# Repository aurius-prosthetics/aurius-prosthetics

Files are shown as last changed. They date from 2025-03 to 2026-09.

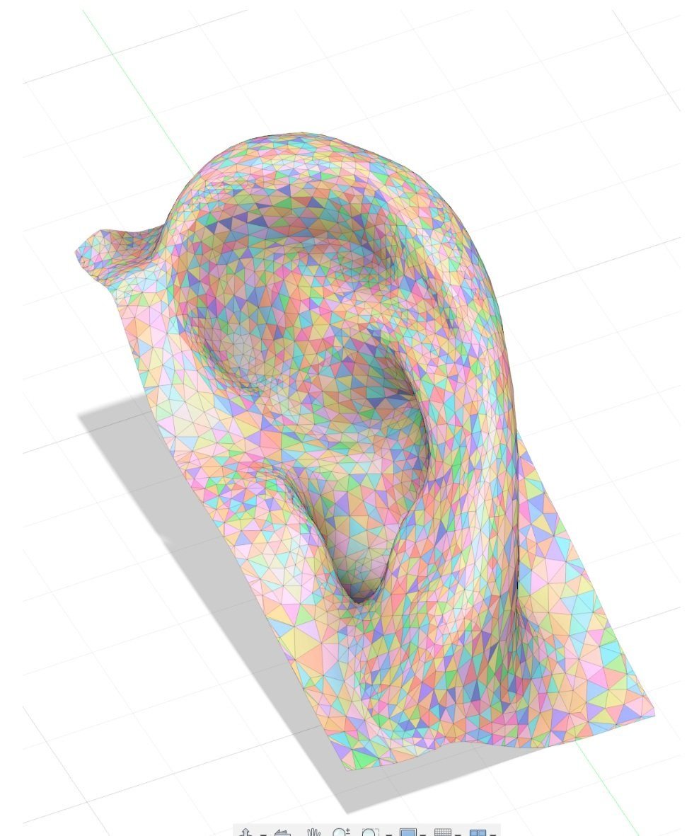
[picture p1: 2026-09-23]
images/front_img3.jpg

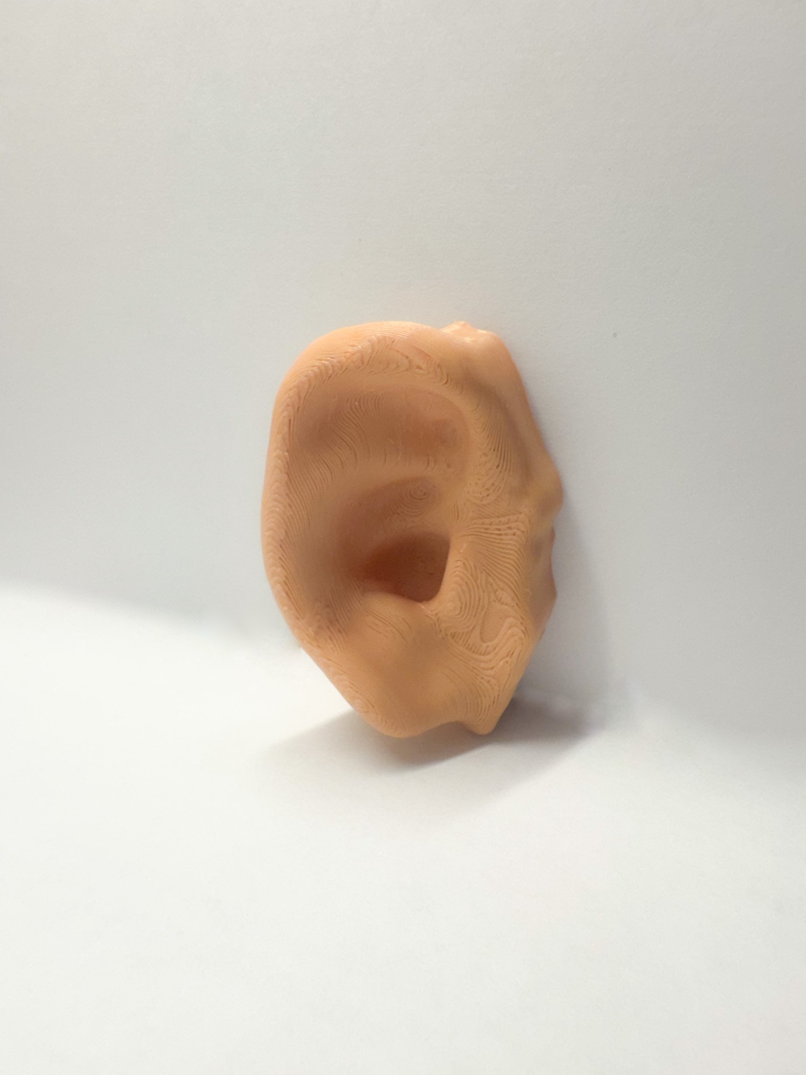
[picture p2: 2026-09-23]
images/gallery_ear.jpg

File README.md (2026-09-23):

# Aurius Prosthetics 🦻




**Open-source initiative for 3D-printed prosthetics**

[📧 Contact Us](mailto:aurius.king@gmail.com)
---
Access our Website : (https://aurius-prosthetics.github.io/aurius-prosthetics/#home)
## About Aurius

Hi, I'm King Oung, founder of Aurius Prosthetics. We're revolutionizing accessibility in prosthetic ear design through cutting-edge 3D printing technology. Our mission is to provide **affordable, accessible, and aesthetically realistic** prosthetic solutions for individuals with microtia, empowering them with greater confidence and self-expression.

By leveraging innovative materials and user-centered design, we bridge the gap between medical necessity and personal identity, ensuring everyone has access to high-quality, customizable prosthetics.

## ✨ Key Features

- **🎨 Customizable Design** - Personalized ear shapes and sizes
- **💰 Cost-Effective** - Open-source designs reduce costs dramatically
- **📐 Precision Crafted** - Generated using LiDAR technology for accurate proportions
- **🧲 Multiple Attachment Options** - Magnetic, clip-on, or suction mounting
- **🤝 Community-Driven** - Open-source CAD files for collaboration
- **🪶 Lightweight & Realistic** - Skin-like texture using flexible materials

## 🚀 Quick Start

### What You'll Need
- 3D printer compatible with flexible filaments
- **Recommended Filament:** Filaflex 82A or similar TPE/TPU
- Basic assembly tools

### Printing Process
1. **Download** your desired `.3MF` file from the [models folder](./models)
2. **Print** using TPE/TPU filament for flexibility (PLA works for prototypes)
3. **Assemble** following our detailed guide
4. **Customize** using provided CAD files as needed

*Compatible with Bambu Labs printers - adjust settings accordingly*

## 📁 Repository Structure

```
aurius-prosthetics/
├── models/                    # 3D printable files
│   ├── Ear1.3mf              # Prosthetic ear model #1
│   ├── Ear2.3mf              # Prosthetic ear model #2
│   ├── Ear3.3mf              # Prosthetic ear model #3
│   └── README Before Printing.md  # Important pre-print instructions
├── HowToPrint.md             # Step-by-step printing instructions
├── assembly-guide.md         # Assembly and attachment methods
├── material-specs.md         # Material specifications and settings
├── CONTRIBUTING.md           # Guidelines for contributors
├── LICENSE                   # MIT License
├── index.html               # Project website page
└── README.md                # This file
```

## 📖 Detailed Guides

- [🖨️ **Printing Guide**](./HowToPrint.md) - Step-by-step printing instructions
- [🔧 **Assembly Guide**](./assembly-guide.md) - Attachment methods and fitting  
- [📋 **Material Specifications**](./material-specs.md) - Filament types and properties

## 🛣️ Roadmap

- [x] **Phase 1:** Initial prototype development (LiDAR scanning, modeling)
- [x] **Phase 2:** Testing attachment methods and materials
- [x] **Phase 3:** Community feedback integration
- [x] **Phase 4:** Global Medical professional collaboration

## 🤝 Contributing

We welcome contributions from the community! Whether you're a:
- **Developer** - Improve CAD designs or documentation
- **Medical Professional** - Provide clinical insights
- **User** - Share feedback and experiences
- **Maker** - Test prints and suggest improvements

## 💬 Community & Support

- **Questions?** Reach out directly to us at [aurius.king@gmail.com] or on social media
- **Success Stories** - We'd love to hear about your prints!
- **Medical Consultation** - Always consult healthcare professionals for medical advice

## 📄 License

This project is licensed under the [MIT License](LICENSE) - see the LICENSE file for details.

## 🙏 Acknowledgments

Special thanks to:
- The open-source community for inspiration and support
- Medical professionals providing guidance
- Early adopters and testers
- Everyone working to make assistive technology more accessible

---

**Made with ❤️ for accessibility and inclusion**

*Aurius Prosthetics - Reimagining the future of prosthetic innovation*

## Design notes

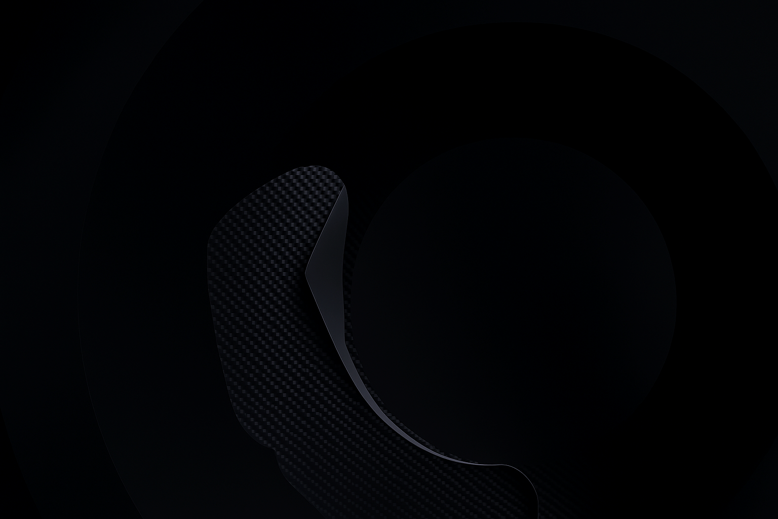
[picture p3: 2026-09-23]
images/hero.png

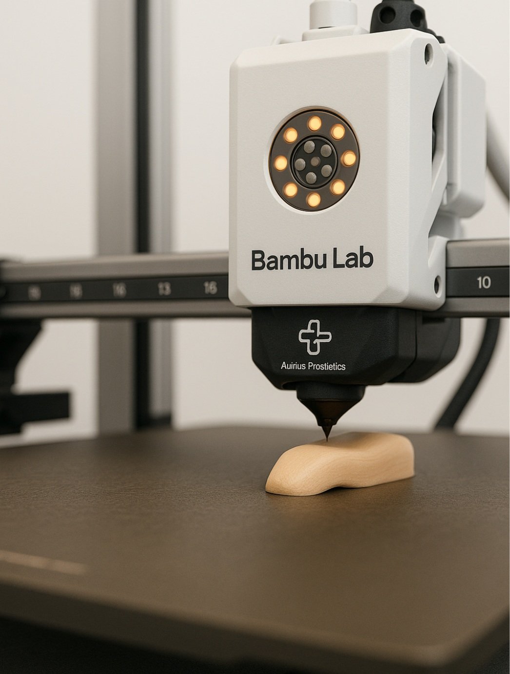
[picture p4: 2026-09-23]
images/front_bg.jpg

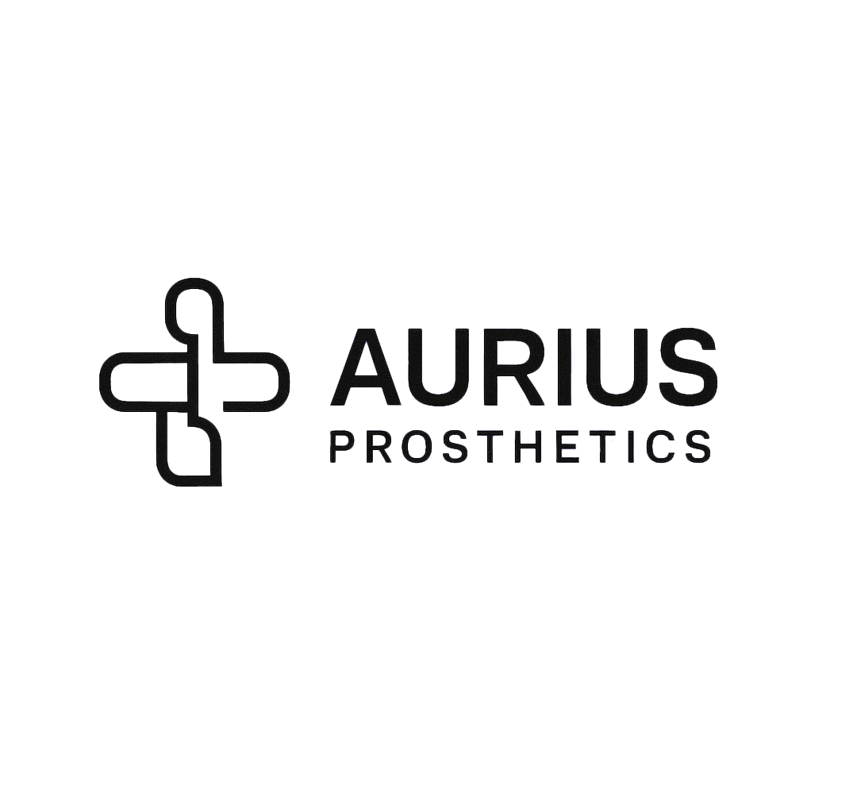
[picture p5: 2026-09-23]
images/front_img5.png

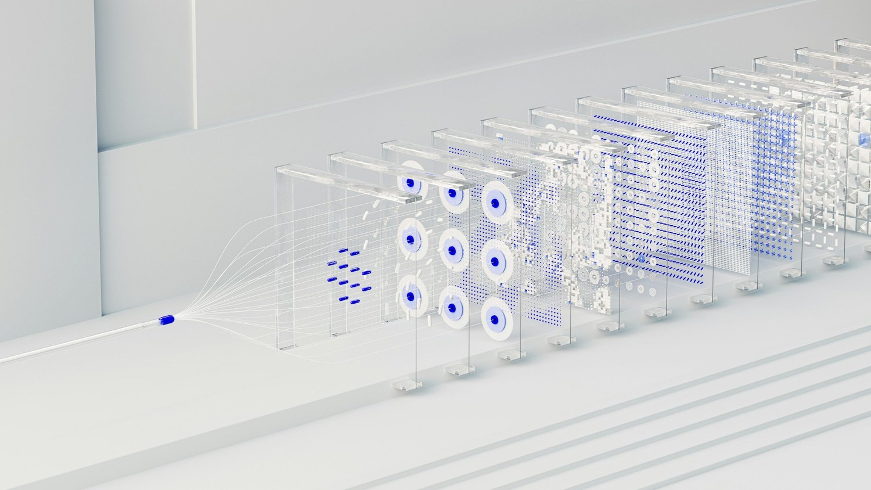
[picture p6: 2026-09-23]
images/contact_bg.jpg

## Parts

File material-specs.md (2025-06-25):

# Material Specifications 📋

## Recommended Filaments

### Primary Choice: TPE/TPU (Flexible)
**Recommended Brand: Filaflex 82A**

#### Properties:
- **Shore Hardness:** 82A (optimal flexibility)
- **Skin-like texture** and feel
- **Excellent durability** for daily wear
- **UV resistant** for long-term use
- **Biocompatible** materials safe for skin contact

#### Print Settings for TPE/TPU:
- **Print Temperature:** 210-230°C
- **Bed Temperature:** 40-60°C
- **Print Speed:** 15-25 mm/s (slow for best quality)
- **Layer Height:** 0.2-0.3mm
- **Infill:** 20-40% (higher for more a more resilience in texture)
- **Supports:** Usually not needed due to the shape of ear prosthetics

### Alternative: PLA (Rigid - For Prototypes)
**Use Case:** Testing fit, prototyping, demonstration models

#### Properties:
- **Easy to print** - beginner friendly
- **Good detail resolution**
- **Not suitable for daily wear** (too rigid)
- **Lower cost** for testing

#### Print Settings for PLA:
- **Print Temperature:** 190-220°C
- **Bed Temperature:** 50-70°C
- **Print Speed:** 40-60 mm/s
- **Layer Height:** 0.1-0.2mm
- **Infill:** 15-25%

## Printer Compatibility

### Optimal Printers:
- **Bambu Lab Series** (A1, X1, P1P, P1S)
  - Excellent with provided .3MF files
  - Automatic settings optimization
  - Reliable flexible filament handling

### Compatible Printers:
- **Prusa i3 MK3S+/MK4**
- **Ender 3 Series** (with direct drive upgrade recommended)
- **Ultimaker Series**
- **Any printer with direct drive extruder (Due to difficulty of printing TPE/TPU)**

### Important Notes:
- **Direct drive extruders** work best with flexible filaments
- **Bowden setups** may struggle with TPE/TPU
- **Enclosed chambers** help with temperature stability

## Material Safety

### Biocompatibility:
- All recommended materials are **skin-safe**
- **FDA approved** food-grade materials
- **No toxic fumes** during normal printing
- **Hypoallergenic** properties

### Cleaning & Maintenance:
- **Wash with mild soap** and warm water
- **Avoid harsh chemicals** or solvents
- **Air dry completely** before use
- **Inspect regularly** for wear or damage

## Sourcing Materials

### Where to Buy:
- **Recreus (Filaflex):** [filaflex.com](https://filaflex.com)
- **Amazon:** Search "TPU 82A filament" There are a wide variety of options
- **Prusament TPU:** [prusa3d.com](https://prusa3d.com)
- **eSUN eTPU:** Available at most 3D printing suppliers

### Cost Considerations:
- **TPE/TPU:** $25-40 per kg
- **PLA (testing):** $15-25 per kg
- **One prosthetic uses:** ~20-50g of material
- **Cost per print:** $0.50-2.00 in materials

## Storage & Handling

### Filament Storage:
- **Keep dry** - use sealed containers with desiccant
- **Room temperature** storage
- **Avoid direct sunlight**
- **TPU can be more sensitive** to moisture than PLA
- Store TPU in a dry space to ensure optimal printing

### Print Preparation:
- **Dry filament** if exposed to humidity
- **Clean print bed** with isopropyl alcohol
- **Check nozzle** for clogs before printing
- **Level bed carefully** for first layer adhesion

## Troubleshooting Common Issues

### Under-Extrusion:
- Increase print temperature by 5-10°C
- Slow down print speed
- Check for filament path obstructions

### Poor Bed Adhesion:
- Increase bed temperature
- Use adhesion aids (painter's tape, PEI sheet)
- Ensure proper first layer height

### Stringing:
- Enable retraction settings
- Lower print temperature slightly
- Increase travel speed

### Layer Separation:
- Increase layer adhesion temperature
- Reduce cooling fan speed
- Check for drafts affecting print

---

**Need Help?** Contact us at [aurius.king@gmail.com](mailto:aurius.king@gmail.com) or visit [aurius.tw](https://aurius.tw)

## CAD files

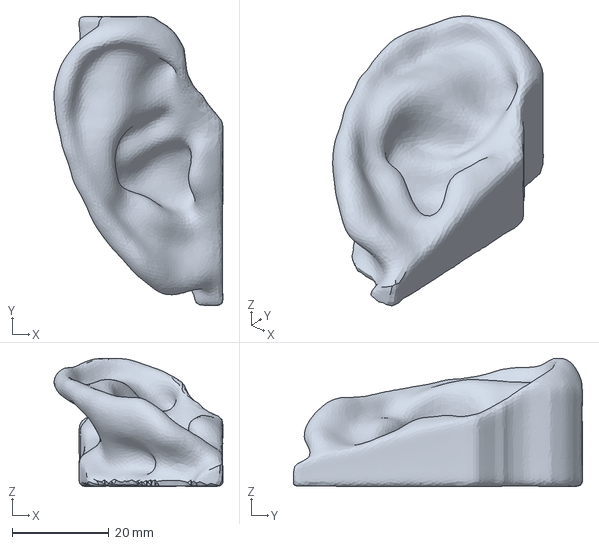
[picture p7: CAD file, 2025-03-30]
models/Ear3.3mf
34.9 x 59.7 x 26.5 mm

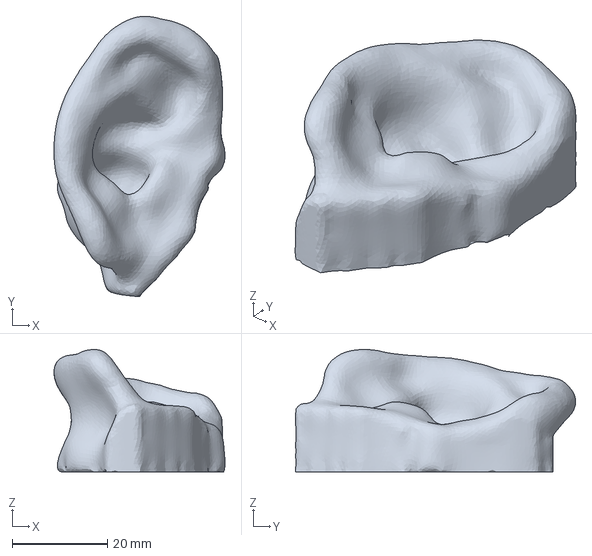
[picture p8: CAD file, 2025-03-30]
models/Ear2.3mf
35.9 x 58.9 x 31.2 mm

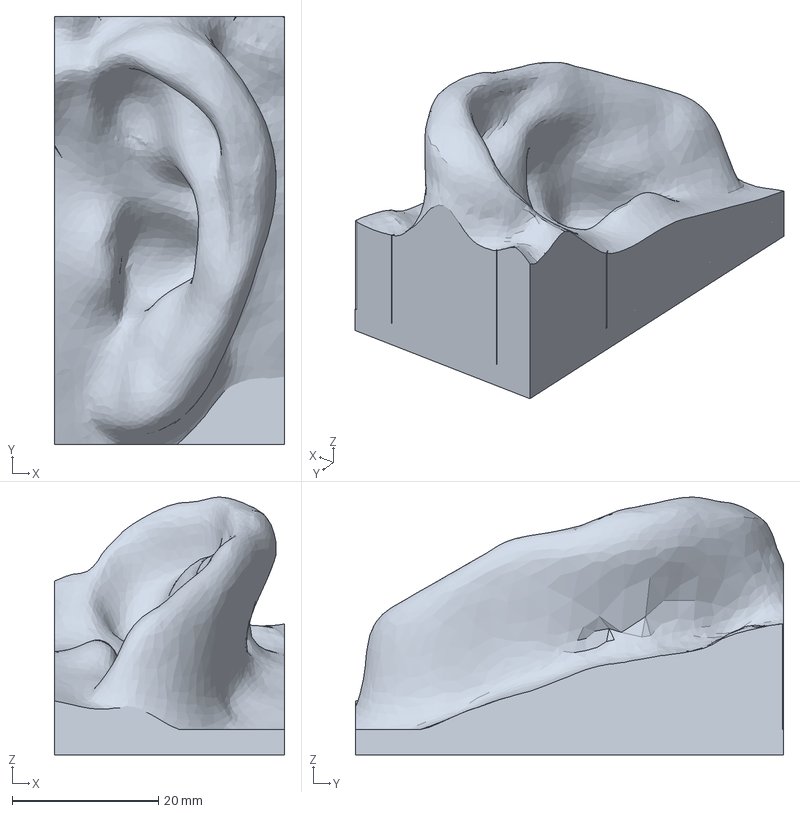
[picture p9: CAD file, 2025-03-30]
models/Ear1.3mf
31.5 x 58.5 x 35.2 mm

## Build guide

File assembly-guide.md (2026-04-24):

# Assembly Guide 🔧

## Overview

This guide walks you through the three main attachment methods for your open-source Aurius prosthetic ear. Choose the method that best suits your comfort level and lifestyle needs.

## Attachment Methods

### 1. Magnetic Attachment 🧲
**Best for:** Easy daily removal, secure hold, minimal skin contact

#### What You'll Need:
- Neodymium Magnetic Tape (N52 grade recommended)
- Medical-grade adhesive or implant-safe magnets
- Optional: Magnetic base plate

#### Basic Installation Steps:
1. **Position the magnets** Around the base of the 3D Printed Prosthetic
2. **Test magnetic strength** - should hold securely but remove easily
3. **Apply counterpart magnet** to attachment point
4. **Test fit and adjustment** for comfort

## Pre-Assembly Checklist

### Print Quality Check:
- [ ] **Surface smooth** - no rough edges or layer lines
- [ ] **Proper flexibility** (for TPU prints)
- [ ] **Correct dimensions** - compare to measurements
- [ ] **No printing defects** - gaps, holes, or weak spots

### Post-Processing:
- [ ] **Remove support material** carefully
- [ ] **Sand rough edges** with fine-grit sandpaper
- [ ] **Test flexibility** and stress points
- [ ] **Clean thoroughly** with mild soap and water

## Customization Options

### Size Adjustments:
- **Scaling in CAD** software before printing
- **Post-print modification** with careful sanding
- **Professional fitting** consultation available

### Color Matching:
- **Skin tone filaments** available from specialty suppliers
- **Post-print painting** with skin-safe paints
- **Custom color mixing** for perfect match

### Texture Modifications:
- **Surface texturing** for more realistic appearance
- **Matte finishing** to reduce shine
- **Vein pattern addition** for enhanced realism

## Safety Guidelines

### Daily Use:
- **Remove before sleeping** (recommended)
- **Clean daily** with mild soap and water
- **Inspect regularly** for wear or damage
- **Replace if damaged** - don't repair with unsafe materials

### Skin Health:
- **Monitor attachment site** for irritation
- **Rotate attachment points** if possible
- **Use hypoallergenic materials** only
- **Consult dermatologist** if skin issues develop

### Activity Considerations:
- **Swimming:** Remove or use waterproof adhesive
- **Sports:** Consider more secure attachment method
- **Medical procedures:** Inform healthcare providers

## Maintenance Schedule

### Daily:
- [ ] Gentle cleaning with soap and water
- [ ] Visual inspection for damage
- [ ] Proper storage when not in use

### Weekly:
- [ ] Deep cleaning with appropriate solution
- [ ] Check attachment mechanism function
- [ ] Inspect for wear patterns

### Monthly:
- [ ] Comprehensive fit assessment
- [ ] Replace adhesive materials if used
- [ ] Document any changes needed

## Troubleshooting

### Common Issues:

**Poor Fit:**
- Recheck measurements against original scan
- Consider reprinting with size adjustments
- Add padding or remove material as needed

**Attachment Problems:**
- Check magnet strength and positioning
- Verify clip tension and padding
- Replace adhesive materials

**Comfort Issues:**
- Sand rough areas carefully
- Add soft padding materials
- Consider different attachment method

**Appearance Concerns:**
- Adjust color matching
- Modify surface texture
- Consult for professional finishing

## Getting Help

### Professional Support:
- **Medical consultation** for attachment options
- **Prosthetic specialist** for complex fitting issues
- **3D printing service** for technical problems

### Community Resources:
- **GitHub Issues** for technical questions
- **User forums** for shared experiences
- **Video tutorials** (coming soon)

### Contact Information:
- **Email:** [aurius.king@gmail.com](mailto:aurius.king@gmail.com)
- **Website:** [aurius.tw](https://aurius.tw)
- **Emergency fitting issues:** Consult medical professional immediately

---

**Remember:** Take your time with fitting and don't hesitate to seek professional help if needed. Your comfort and safety are our top priorities.

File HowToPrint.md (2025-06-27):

# How to 3D Print Prosethetic Ears 🦻

## Downloading Files & Presets
  Download the appropriate files in the **models** folder. I have included a couple different template versions that you can choose from, and they are all in the .3mf file, which can be directly exported to Bambu Studio. After downloading the file and opening it in Bambu Studio, download the appropriate **print preset** and **filament preset** and import it to the Bambu slicer. 
  The presets I have included in the PrintPreset folder is for the Filaflex 82a filament, which can be purchased here: 
  
  https://recreus.com/en-en/products/filaflex-82a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

  If you have a slightly different TPU or with a similar shore hardness, you could try using the presets, which should still work, but may need some fine tuning. If you are printing in PLA, normal settings should work fine since it is a lot less complex.

### Creating a Custom Ear
To create your own custom ear instead of using one of my presets is simple as well, simply follow the steps below
1. Download Polycam (mobile app)
2. Use Polycam’s  LiDAR scanning to render a human ear
3. Trim the rendering to only include the ear/necessary parts
4. Export as STL file, send to Fusion 360 or MeshMixer to patch/repair holes
5. Send STL file to MeshMixer (Online Application) to add a base/ make the render a solid
6. Export as 3MF file to Bambu Studio, adjust final settings, print.

## Printing
  To print, simply slice the plate with all the presets included, then press print plate to send it to your 3D Printer.
  As for the 3D Printers, I used the Bambu Labs A1 without AMS, which works fine. Other similar printers should work great too, just remember not to use AMS and just use the external spool, since TPU tends to clog and get stuck in the AMS tubes. 
  The included Textured PEI plate also works, but it can have some tricky bed adhesion problems, just make sure you keep the plate clean, and be patient when removing the finalized print from the bed. Use a razor blade or a sharp tool to slowly detach the model from the bed.

### Printing Precautions
  One of the most important things about printing in TPU is **to print slow**. This is the most important setting no matter what type of TPU you are using, and I recommend trying to print at around 15-25 mm/s, just to get a high quality print. 
If you have any questions while printing, feel free to contact me at aurius.king@gmail.com

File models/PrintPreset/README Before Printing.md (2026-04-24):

# Disclaimers Before Printing 
Here are a few issues and tips that I found while experimenting, which will help you reduce errors and get better quality print results

## Printing with TPU
Printing with PLA works well, it is consistent, strong, and cheap/accessible. However, it is hard and doesn’t mimic a real ear 
Printing with TPU, such as Filaflex 82a can mimic the softness of a real ear, but it is very difficult to get right, here are some things I encountered on my first print:
Settings for printing TPU: TPU needs to be tuned with a lot of different settings: print speed, nozzle and bed heating, speed, fan cooling settings, length, retraction, flow, layer height, etc.
TPU also needs to be especially calibrated/fitted for your printer, for the Bambu Labs A1, you cannot use AMS and you have to manually input the external filament as TPU in settings so that your printer know it is TPU.

Here are some problems I encountered on my first print: 
Bed Adhesion: TPU sticks to the bed, it is hard to scrape off the print without damaging the bottom layer
Stringing/inconsistent flow, the flow of the filament can become inconsistent due to the softness of the filament, it can get clogged etc, You cannot print on fast speeds, around 30 mms for all parts is a good.
Nozzle width, TPU seems so shrink when printing, there are a lot of small holes that appear when you print, which has to do with flow, nozzle sizes, and MOST IMPORTANTLY: Print Speed.
TPU will take much longer to print if you want a high quality print compared to PLA, you have to print extremely slow, around 10mm/s-30mm/s
If you live in a humid environment, or even if there is just some moisture in the air, leaving your TPU out could reduce print quality as the filament performs poorly when absorbing moisture.

During the second/third print, I lowered speeds even more, roughly 20 mm/s for all sections, which improved print quality dramatically
I also lowered nozzle temperature to 220 degrees celsius, which also helped make the print smoother.
I increased the flow ratio of the filament to 1.2 so that more filament is extruded in order to try and fill in the small gaps and holes that are created on the first print. (TPU Tends to shrink under heat, so a high flow ratio may be helpful.
I also increased the line width of the overall project to 0.45mm, while increasing the top and bottom layers to 0.5mm for a fuller finish
Lastly, I waited for the print plate to cool down, to room temperature, before using a thin razor and carefully detaching the print from the plate.
I highly recommend you to tweak around with the settings a little bit. Be sure to watch the first layer of the print to make sure everything works well, and that the print quality is good.

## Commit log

2025-03-30 Initial Upload
    [King Ear Render v3.3mf, dadearv2.3mf, jerryearfinalhopefully.3mf]
2025-03-30 Rename Kingolele Ear Render v3.3mf to Ear1 v3.3mf
    [Ear1 v3.3mf]
2025-03-30 Rename Ear1 v3.3mf to Ear1.3mf
    [Ear1.3mf]
2025-04-13 Added Bambu Studio printer preset
2025-04-13 Rename Bambu Lab A1 0.4 nozzle.bbscfg to PRINT PRESET for Bambu Studios
2025-04-13 Create Read Before Printing
2025-04-13 Rename models/PRINT PRESET for Bambu Studios to models/PrintPreset/PRINT PRESET for Bambu Studios
2025-04-13 Update and rename Read Before Printing to README Before Printing
2025-04-13 Rename PRINT PRESET for Bambu Studios to .zip PRINT PRESET for Bambu Studios
2025-04-13 added .zip files for printing
2025-04-13 Rename .zip PRINT PRESET for Bambu Studios to PRINT PRESET for Bambu Studios
2025-04-13 Rename Filament presets.zip to TPU Filaflex 82a Filament presets.zip
2025-04-13 Rename Printer presets.zip to !Printer presets.zip
2025-04-13 Rename TPU Filaflex 82a Filament presets.zip to !TPU Filaflex 82a Filament presets.zip
2025-04-27 Rename README Before Printing to README Before Printing.md
2025-06-27 Update README Before Printing.md
2026-04-24 Fix formatting and clarify TPU printing issues
    Corrected formatting and clarified issues encountered when printing with TPU, including bed adhesion, stringing, nozzle width, and print speed.
